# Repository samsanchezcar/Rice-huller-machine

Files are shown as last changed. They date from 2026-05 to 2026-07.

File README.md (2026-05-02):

<div align="center">

# DAMSPI-150
## Descascaradora de Arroz Modular Semiautomática con Pesaje Integrado

**Proyecto Aplicado de Ingeniería — 2017275 | 1er Semestre 2026**
**Universidad Nacional de Colombia · Facultad de Ingeniería · Grupo B**






</div>

---

## Tabla de Contenido

1. [Resumen Ejecutivo](#1-resumen-ejecutivo)
2. [Equipo de Trabajo](#2-equipo-de-trabajo)
3. [Estructura del Repositorio](#3-estructura-del-repositorio)
4. [Arquitectura del Sistema](#4-arquitectura-del-sistema)
5. [Guía de Fase del Proyecto](#5-guía-de-fase-del-proyecto)
6. [Proveedores Clave](#6-proveedores-clave)
7. [Instrucciones de Uso](#7-instrucciones-de-uso)
8. [Estado de Componentes](#8-estado-de-componentes)
9. [Pendientes por Fase](#9-pendientes-por-fase)
10. [Normas y Convenciones del Repositorio](#10-normas-y-convenciones-del-repositorio)

---

## 1. Resumen Ejecutivo

El **DAMSPI-150** es un equipo semiautomático para el descascarillado de arroz paddy (*Oryza sativa*) diseñado para operar en campo, sin acceso a red eléctrica, con capacidad de **150 kg/h**. Surge de la necesidad de los pequeños y medianos productores de arroz de la región de Neiva (Huila) de reducir su dependencia de los molinos industriales y aumentar el valor agregado de su producto en origen.

El sistema está organizado en **4 módulos desmontables** con peso máximo de 25 kg cada uno, permitiendo su transporte y montaje por dos o tres personas sin herramientas especializadas. Incorpora un **sistema de control automático de pesaje** que detiene el proceso al alcanzar el peso de un bulto objetivo (10, 25 o 50 kg), accionando el embrague electromagnético y la compuerta de la tolva.

| Parámetro | Valor |
|---|---|
| Nombre del sistema | DAMSPI-150 |
| Solicitante | Diego Alexander Castro Neira — Diego Castro Industria y Construcción S.A.S. |
| Capacidad objetivo | 150 kg/h de arroz paddy (humedad 18–22%) |
| Motor | Gasolina 6.5 HP / 3600 RPM (ya adquirido) |
| Módulos | 4 módulos desmontables (Potencia, Descascarillado, Control/Pesaje, Chasis) |
| Peso máx. por módulo | ≤ 25 kg |
| Presupuesto total | $7.000.000 COP (aportado por solicitante) |
| Presupuesto estimado | ~$5.980.000 COP (margen de ~$1.020.000) |
| Microcontrolador | PIC18F4550 |
| Interfaz de usuario | LCD 20×4 I2C + Teclado matricial 4×4 |
| Embrague | Electromagnético DC 24V — DLD6-05 tipo A |
| Eficiencia descascarillado | ≥ 85% en primera pasada |
| Precisión pesaje | ±100 g |
| Tiempo de ensamble | ≤ 60 minutos |
| Piezas estructurales | Manufactura aditiva FDM (PETG / PLA+) con optimización topológica previa |
| Semestre | 1er Semestre 2026 (14 semanas: 3 Feb – 30 May 2026) |

---

## 2. Equipo de Trabajo

| Nombre | Código | Área Principal | Responsabilidades Clave |
|---|---|---|---|
| **Nicolás Herreño Fuentes** | — | Diseño Mecánico (Líder) | Cálculos de transmisión, memorias de cálculo, CAD Onshape, planos de fabricación |
| **Sebastián D. Millan B.** | — | Diseño Mecánico | Cálculos elementos de máquinas, CAD, diseño eje secundario |
| **Andrés G. Pinilla M.** | — | Manufactura y CAD | Talleres externos, Onshape, optimización topológica + FDM |
| **Samuel D. Sánchez C.** | — | Electrónica / Control / **Gestión** | Firmware PIC18F4550, sistema de pesaje, **gestión de proveedores, cotizaciones, BOM, compras**, finanzas |
| **Gabriel E. Bojacá M.** | — | Electrónica / Financiero | Circuito electrónico, PCB, interfaz LCD-teclado, gestión presupuesto |
| **Santiago Ávila C.** | — | Eléctrico / Potencia | Alternador, carga batería, cableado potencia, sistema eléctrico Módulo 1 |

> **Nota de gestión**: Samuel es el responsable único de toda la coordinación con proveedores: contacto inicial, solicitud de cotizaciones, seguimiento de pedidos, recepción de componentes y registro en el BOM. Toda compra debe quedar registrada antes de ejecutarse.

---

## 3. Estructura del Repositorio

```
DAMSPI-150/
│
├── README.md                          ← Este archivo — guía maestra del proyecto
│
├── 01_Informe/                        ← Informes de avance (Partes I, II y III)
│   ├── Informe_Avance_Parte_I_Descascaradora.docx   ← Entrega S4 (completada)
│   ├── Informe_Parte_II_Diseño_Detallado.docx        ← Entrega S8 (en progreso)
│   ├── Informe_Parte_III_Final.docx                  ← Entrega S14 (pendiente)
│   ├── boceto_arquitectura_modular.png
│   ├── sistema_potencia_electrica.svg
│   └── Diagramas_bloques.pdf
│
├── 02_Actas/                          ← Actas semanales y documentos legales
│   ├── Acuerdo_Solicitante.pdf        ← AS firmado
│   ├── contrato_social.pdf            ← CS firmado
│   ├── Acta_S01.pdf
│   ├── Acta_S02.pdf
│   ├── Acta_S03.pdf
│   └── Acta_SColchon.pdf
│
├── 03_Cronograma_GANTT/               ← Planificación y seguimiento
│   ├── GANTT_Descascaradora_v2.xlsx   ← GANTT original (referencia)
│   └── GANTT-PAI1B.pdf
│
├── 04_BOM/                            ← Lista de materiales
│   └── BOM_Descascaradora_v1.xlsx     ← BOM con 34 ítems (~$5.98M COP)
│
├── 05_CAD_Planos/                     ← Modelos 3D y planos de fabricación
│   ├── Onshape_Link.md                ← Enlace al modelo Onshape compartido
│   └── (exportar aquí planos PDF/DWG al finalizar cada módulo)
│
├── 06_Estado_del_Arte_Referencias/    ← Literatura técnica y normativa
│   ├── Baker_Tribologia_Molineria_Arroz.pdf
│   ├── Design_Fabrication_Rice_Hulling.pdf
│   ├── Manual_Tecnico_Descascaradora_Referencia.pdf
│   ├── Referencia_Adicional_Procesamiento_Arroz.pdf
│   └── rm05.pdf
│
├── 07_Bitacoras/                      ← Bitácoras semanales individuales
│   ├── Bitacora_Nicolas.md
│   ├── Bitacora_Sebastian.md
│   ├── Bitacora_Andres.md
│   ├── Bitacora_Samuel.md
│   ├── Bitacora_Gabriel.md
│   └── Bitacora_Santiago.md
│
├── 08_Electronica/                    ← Todo lo electrónico (MCU, sensores, firmware)
│   ├── GUIA_ELECTRONICA.md            ← Guía técnica electrónica completa ★
│   ├── firmware/                      ← Código fuente PIC18F4550
│   │   ├── DAMSPI150.X/              ← Proyecto MPLAB X
│   │   └── LibLCD_I2C_XC8.h         ← Librería LCD I2C para XC8
│   └── esquematicos/                  ← Esquemáticos del circuito de control
│
├── 09_Electrica/                      ← Todo lo eléctrico (potencia, alternador, batería)
│   ├── GUIA_ELECTRICA.md             ← Guía técnica eléctrica-potencia completa ★
│   └── diagramas/                     ← Diagramas del sistema de potencia eléctrica
│
└── 10_Gestion/                        ← Gestión del proyecto
    ├── GESTION_PROYECTO.md            ← EDT detallado + Gantt + gestión compras ★
    ├── REGISTRO_PROVEEDORES.md        ← Contactos, cotizaciones y seguimiento (Samuel)
    └── CONTROL_PRESUPUESTO.md        ← Control de gastos vs. presupuesto
```

> Los archivos marcados con **★** son documentos técnicos vivos que deben actualizarse semanalmente.

---

## 4. Arquitectura del Sistema

El DAMSPI-150 se organiza en cuatro módulos funcionales independientes:

```
┌─────────────────────────────────────────────────────────────────────┐
│                    DAMSPI-150 — VISTA FUNCIONAL                     │
├──────────────┬──────────────────┬──────────────────┬───────────────┤
│  MÓDULO 1    │    MÓDULO 2      │    MÓDULO 3       │  MÓDULO 4     │
│  POTENCIA    │  DESCASCARILLADO │  CONTROL/PESAJE   │  CHASIS       │
│              │                  │                   │               │
│ Motor 6.5HP  │  Rodillos PU     │  PIC18F4550       │  Estructura   │
│ Alternador   │  Ø80mm / 200mm   │  LCD 20×4 I2C     │  acero 40×40  │
│ Batería 24V  │  Ventilador      │  Teclado 4×4      │  Chasis       │
│ Embrague     │  centrífugo      │  HX711 + 4 celdas │  soldado      │
│ Boost 14→24V │  Sin Fín alim.   │  SSR + Embrague   │  Ruedas       │
│ Buck 24→5V   │  Pulidora horiz. │  Servo tolva      │  Pasadores    │
│              │  (opcional)      │  Pilotos / Buzzer │  conex. rápida│
│  ~22 kg      │  ~18 kg          │  ~8 kg            │  ~15 kg       │
└──────────────┴──────────────────┴──────────────────┴───────────────┘
       │                │                  │                │
       └────────────────┴──────────────────┴────────────────┘
                    Correas en V / Poleas / Ejes de transmisión
```

**Documentación técnica por área:**

| Área | Documento | Responsable |
|---|---|---|
| Sistema electrónico (MCU, firmware, sensores, interfaz) | [`08_Electronica/GUIA_ELECTRONICA.md`](08_Electronica/GUIA_ELECTRONICA.md) | Samuel, Gabriel |
| Sistema eléctrico (potencia, alternador, batería, carga) | [`09_Electrica/GUIA_ELECTRICA.md`](09_Electrica/GUIA_ELECTRICA.md) | Santiago, Samuel |
| Gestión, EDT, Gantt, proveedores, compras | [`10_Gestion/GESTION_PROYECTO.md`](10_Gestion/GESTION_PROYECTO.md) | Samuel |

---

## 5. Guía de Fase del Proyecto

### Semana Actual → Ver `10_Gestion/GESTION_PROYECTO.md` para detalle completo

| Fase | Semanas | Estado | Entregable |
|---|---|---|---|
| **F1** — Formulación y requisitos | S1–S3 | ✅ Completada | Informe Parte I |
| **F2** — Diseño Módulo Potencia | S3–S6 | 🔄 En progreso | Memorias cálculo + CAD |
| **F3** — Diseño Electrónico y Control | S4–S7 | 🔄 En progreso | Circuito + Firmware |
| **F4** — Diseño Módulo Descascarillado | S3–S8 | 🔄 En progreso | Informe Parte II |
| **F4G** — Gestión proveedores y compras | S3–S10 | 🔄 En progreso | Registro Proveedores |
| **F5** — Manufactura y montaje | S8–S12 | ⏳ Pendiente | Prototipo ensamblado |
| **F6** — Validación y pruebas | S12–S13 | ⏳ Pendiente | Video + resultados |
| **F7** — Documentación y entrega | S13–S14 | ⏳ Pendiente | Informe Parte III |

### Checklist de la Semana en Curso

Antes de cada reunión semanal, verificar:

- [ ] Acta de la semana anterior firmada y archivada en `02_Actas/`
- [ ] Bitácoras individuales actualizadas en `07_Bitacoras/`
- [ ] BOM actualizado con nuevas adquisiciones o cotizaciones (`04_BOM/`)
- [ ] Samuel: actualizar `10_Gestion/REGISTRO_PROVEEDORES.md` con estado de pedidos
- [ ] Avance de CAD subido a Onshape (link en `05_CAD_Planos/Onshape_Link.md`)
- [ ] Samuel/Gabriel: commits de firmware en `08_Electronica/firmware/`
- [ ] GANTT actualizado con estado real de avance

---

## 6. Proveedores Clave

| Proveedor | Productos | Contacto | Responsable |
|---|---|---|---|
| **Solagro Colombia** | Rodillos PU Ø80mm, pulidora horizontal, repuestos | solagro.co/repuestos | Samuel |
| **MercadoLibre Colombia** | Embrague DLD6-05, SSR, electrónica general | mercadolibre.com.co | Samuel |
| **AliExpress** | Celdas de carga tipo S, PIC18F4550, batería LiFePO4, LCD 20×4, teclado 4×4 | aliexpress.com | Samuel |
| **Homecenter** | Motor 6.5HP (ya adquirido) | homecenter.com.co | — |
| **Ferreterías industriales Bogotá** | Perfiles acero, tornillería, rodamientos, poleas | Local Bogotá | Gabriel / Samuel |
| **Taller externo UNAL** | Mecanizado ejes, soldadura chasis | Campus UNAL | Nicolás, Andrés |
| **Naylampmechatronics** | HX711, electrónica | naylampmechatronics.com | Samuel |
| **Siesa Industrial** | E-Stop, pilotos LED industriales | Local Bogotá | Samuel |

> **Ver detalle completo de cotizaciones y contactos en:** [`10_Gestion/REGISTRO_PROVEEDORES.md`](10_Gestion/REGISTRO_PROVEEDORES.md)

---

## 7. Instrucciones de Uso

### Informe Principal
1. Abrir `01_Informe/Informe_Avance_Parte_*.docx` en Word/Google Docs
2. Actualizar tabla de contenido: **Referencias → Actualizar tabla → Todo el documento**
3. No modificar estructura de secciones sin actualizar el TOC

### BOM
- Abrir `04_BOM/BOM_Descascaradora_v1.xlsx`
- Totales calculados automáticamente (columna H = E × G)
- **Columna Estado**: `ADQUIRIDO` / `COTIZADO` / `Por adquirir` / `Por adquirir (Solagro)`
- Actualizar inmediatamente al recibir cualquier componente o cotización
- Samuel notifica al grupo cada actualización

### GANTT
- Abrir `03_Cronograma_GANTT/GANTT_Descascaradora_v2.xlsx`
- Actualizar al inicio de cada semana con estado real
- EDT completo y mejorado en `10_Gestion/GESTION_PROYECTO.md`

### Firmware (Electrónica)
- Abrir `08_Electronica/firmware/DAMSPI150.X/` con **MPLAB X IDE ≥ 6.0**
- Compilador: **XC8 ≥ 3.0**
- Programador: **PICkit 3 o PICkit 4** (ICSP)
- Ver documentación completa en `08_Electronica/GUIA_ELECTRONICA.md`

### CAD (Onshape)
- Link al modelo compartido en `05_CAD_Planos/Onshape_Link.md`
- Exportar planos PDF/DWG a `05_CAD_Planos/` al completar cada módulo
- Usar prefijo de versión: `v1.0_`, `v1.1_`, etc.

---

## 8. Estado de Componentes

| N° | Componente | Módulo | Precio Unit. | Estado | Resp. |
|----|---|---|---|---|---|
| 1 | Motor gasolina 6.5HP | Mod.1 | $750.000 | ✅ ADQUIRIDO | — |
| 2 | Embrague DLD6-05 24V | Mod.1 | $300.000 | 📋 COTIZADO | Samuel |
| 3 | Celda de carga tipo S 10kg ×4 | Mod.3 | $57.045 c/u | 📋 COTIZADO | Samuel |
| 4 | PIC18F4550 DIP-40 | Mod.3 | $31.018 | 📋 COTIZADO | Samuel |
| 5 | Batería LiFePO4 24V/5Ah | Mod.1 | $250.000 | 📋 COTIZADO | Santiago |
| 6 | HX711 ADC 24 bits | Mod.3 | $15.000 | 🛒 Por adquirir | Samuel |
| 7 | LCD 20×4 + módulo I2C | Mod.3 | $25.000 | 🛒 Por adquirir | Samuel |
| 8 | Teclado matricial 4×4 | Mod.3 | $15.000 | 🛒 Por adquirir | Samuel |
| 9 | Rodillos PU Ø80mm (par) | Mod.2 | $400.000 | 🔍 Solagro | Samuel |
| 10 | Pulidora horizontal | Mod.2 | $600.000 | 🔍 Solagro | Samuel |
| 11 | Alternador motocicleta | Mod.1 | $180.000 | 🛒 Por adquirir | Santiago |
| … | *(ver BOM completo)* | — | — | — | — |

> Leyenda: ✅ Adquirido | 📋 Cotizado | 🛒 Por adquirir | 🔍 En gestión con proveedor específico

---

## 9. Pendientes por Fase

### Fase Actual (S4–S7) — Diseño Detallado

**Mecánica (Nicolás, Sebastián, Andrés):**
- [ ] Memorias de cálculo: eje secundario, transmisión por poleas
- [ ] Diseño CAD Módulo 2: rodillos, ajustador, ventilador, Sin Fín
- [ ] Diseño CAD Módulo 4: chasis, puntos de conexión rápida
- [ ] Optimización topológica de piezas para FDM (Andrés)
- [ ] Contacto con taller externo para mecanizado de ejes

**Electrónica (Samuel, Gabriel):**
- [ ] Diseño esquemático PCB del circuito de control (Módulo 3)
- [ ] Iniciar firmware: `initPorts()`, `initLCD_I2C()`, `hx711_init()`
- [ ] Selección y pedido: LCD 20×4, teclado 4×4, HX711, SSR

**Eléctrica (Santiago, Samuel):**
- [ ] Diseño detallado: alternador → rectificador → boost → batería
- [ ] Cotización del Boost DC-DC 14V→24V 5A
- [ ] Diseño de canaletas y cableado entre módulos

**Gestión (Samuel):**
- [ ] Contactar Solagro para rodillos y pulidora (cotización formal)
- [ ] Confirmar pedido AliExpress: celdas de carga, PIC, batería
- [ ] Actualizar REGISTRO_PROVEEDORES.md con tiempos de entrega

### Siguiente Entrega (Parte II — Semana 8)
- [ ] Diseño conceptual con bocetos de todos los módulos
- [ ] Diagramas de caja negra y caja gris
- [ ] Memorias de cálculo completas (transmisión, rodillos, ejes)
- [ ] Modelos CAD 3D avanzados en Onshape
- [ ] Planos preliminares de fabricación
- [ ] Cronograma definitivo actualizado

---

## 10. Normas y Convenciones del Repositorio

### Nomenclatura de Archivos
```
[Módulo]_[Descripción]_v[X.Y].[ext]
Ejemplos:
  Mod3_Esquematico_Control_v1.0.pdf
  Mod1_CAD_BaseMotor_v2.1.step
  Acta_S05_20260310.pdf
```

### Versionado de Documentos
- `v1.0` → Primera versión entregable
- `v1.X` → Correcciones menores (sin cambio de estructura)
- `v2.0` → Revisión mayor (cambio de diseño o nueva fase)

### Convenciones de Código (Firmware)
- Comentarios en español
- Funciones: `camelCase` (ej. `realizarTara()`)
- Constantes: `MAYUSCULAS_CON_GUION` (ej. `PESO_OBJETIVO_KG`)
- Un archivo por módulo funcional (ver `08_Electronica/GUIA_ELECTRONICA.md`)

### Actualización del BOM
- Toda compra, cotización o cambio de precio debe registrarse el mismo día
- Samuel envía resumen semanal al grupo por WhatsApp/Discord
- Los precios en el BOM son precios de compra real (no estimados)

---

## Información del Solicitante

| Campo | Valor |
|---|---|
| Nombre | Diego Alexander Castro Neira |
| Empresa | Diego Castro Industria y Construcción S.A.S. |
| NIT | 9009608102 |
| Correo | dicaindustria@gmail.com |
| Teléfono | 315-255-2560 |
| Ubicación de entrega | Neiva, Huila, Colombia |

---

*Versión: 2.0 | Última actualización: Abril 2026 | Equipo Grupo B — PAI 2017275*

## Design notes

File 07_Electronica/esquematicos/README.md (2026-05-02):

# Esquemáticos — Módulo 3 Control y Pesaje

## Archivos a generar (ver GUIA_ELECTRONICA.md §5 para especificaciones)

| Archivo | Descripción | Estado |
|---|---|---|
| `Mod3_Esquematico_Control_v1.0.pdf` | Circuito completo MCU + sensores + actuadores | ⏳ Gabriel S6–S7 |
| `Mod3_Esquematico_Potencia_v1.0.pdf` | Circuito SSR + embrague + pilotos | ⏳ Gabriel S6 |
| `Mod3_PCB_Layout_v1.0.pdf` | Layout PCB para fabricación JLCPCB | ⏳ Gabriel S7–S8 |

## Herramientas recomendadas
- **KiCad 8** (gratuito, exporta Gerbers para JLCPCB)
- **EasyEDA** (alternativa online, integrado con JLCPCB)

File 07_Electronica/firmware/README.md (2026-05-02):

# Firmware DAMSPI-150 — PIC18F4550

## Requisitos

| Herramienta | Versión mínima |
|---|---|
| MPLAB X IDE | 6.0 |
| XC8 Compiler | 3.0 |
| Programador | PICkit 3 o PICkit 4 |

## Compilar

1. Abrir MPLAB X IDE
2. **File → Open Project** → seleccionar carpeta `DAMSPI150.X/`
3. Verificar Device: `PIC18F4550`, Compiler: `XC8`
4. **Clean and Build** (Ctrl+Shift+F11)
5. El `.hex` queda en `dist/default/production/`

## Programar

Conexión ICSP (5 pines):

```
PICkit 4    →   PIC18F4550
─────────────────────────
MCLR (VPP)  →   Pin 1  (MCLR/VPP)
VDD         →   Pin 11 (VDD +5V)
GND         →   Pin 12 (VSS GND)
PGD (ICSPD) →   Pin 40 (RB7/PGD)
PGC (ICSPC) →   Pin 39 (RB6/PGC)
```

## Calibración del Sistema de Pesaje

**Primera vez o tras cambiar celdas de carga:**

1. Dejar la plataforma de pesaje completamente vacía
2. Energizar el sistema → ejecutar tara automática al inicio
3. Colocar una masa de referencia conocida (ej. 5 kg certificados)
4. Leer el valor raw del HX711 (via UART debug en RC6/RC7)
5. Calcular: `factor_calibracion = (raw_con_masa - offset_tara) / masa_kg`
6. Actualizar la constante en el firmware y recompilar, O usar la opción de calibración del menú LCD

## Estructura del Firmware

```
DAMSPI150.c         ← Archivo principal (main + ISR + toda la lógica)
LibLCD_I2C_XC8.h    ← Driver LCD 20x4 via I2C PCF8574
```

## Mapa EEPROM

| Dirección | Contenido |
|---|---|
| 0x00 | Contador de bultos |
| 0x01 | Reservado |
| 0x02 | Peso objetivo (kg, entero) |
| 0x03 | offset_tara byte HI |
| 0x04 | offset_tara byte MID |
| 0x05 | offset_tara byte LO |
| 0x06 | factor_calibracion byte HI |
| 0x07 | factor_calibracion byte LO |

## Pines del PIC18F4550

Ver tabla completa en `08_Electronica/GUIA_ELECTRONICA.md §5.2`

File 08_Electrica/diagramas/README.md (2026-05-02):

# Diagramas Sistema Eléctrico de Potencia

## Archivos a generar (ver GUIA_ELECTRICA.md para especificaciones)

| Archivo | Descripción | Estado |
|---|---|---|
| `Diagrama_Unifilar_Sistema_Electrico_v1.0.pdf` | Diagrama unifilar completo del sistema eléctrico | ⏳ Santiago S8 |
| `Diagrama_Cableado_Modulos_v1.0.pdf` | Cableado entre módulos (colores, secciones, conectores) | ⏳ Santiago S8–S9 |
| `Esquema_Carga_Bateria_v1.0.pdf` | Circuito carga LiFePO4 (alternador → boost → XH-M603 → batería) | ⏳ Santiago S7 |

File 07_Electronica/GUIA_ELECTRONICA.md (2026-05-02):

# GUÍA TÉCNICA DE SISTEMA ELECTRÓNICO
## DAMSPI-150 — Descascaradora de Arroz Modular Semiautomática con Pesaje Integrado
### Proyecto Aplicado de Ingeniería 2017275 — Universidad Nacional de Colombia — Grupo B — 1er Semestre 2026

---

## OBJETIVO GENERAL

Definir, especificar e integrar todos los componentes electrónicos, eléctricos y de control del sistema DAMSPI-150, de manera que el equipo de diseño cuente con una guía técnica detallada, clara y verificable para la adquisición, montaje, programación y validación del subsistema electrónico completo.

---

## OBJETIVOS ESPECÍFICOS

- Describir la arquitectura electrónica completa del sistema, identificando los tres niveles: potencia eléctrica, adquisición de señal y control lógico.
- Especificar técnicamente cada componente electrónico requerido: microcontrolador, módulos de conversión, actuadores, sensores e interfaz de usuario.
- Documentar el diagrama de bloques del sistema de control y el diagrama del sistema de potencia eléctrica.
- Establecer las conexiones eléctricas entre los módulos del sistema de control y los actuadores y sensores.
- Definir los requerimientos de firmware del PIC18F4550 para la gestión del ciclo de pesaje y control del embrague.
- Proveer la lista de materiales electrónicos con referencias comerciales y especificaciones de adquisición.

---

## 1. DEFINICIÓN DEL PROBLEMA ELECTRÓNICO

El sistema DAMSPI-150 opera en campo abierto (zona rural de Neiva, Huila) **sin acceso a la red eléctrica**. La totalidad de la energía eléctrica del sistema electrónico y de control debe ser generada de forma autónoma a partir del motor de gasolina de 6.5 HP ya adquirido. Esto implica un doble problema de ingeniería electrónica:

1. **Generación y acondicionamiento de energía eléctrica**: El motor mecánico debe alimentar un sistema eléctrico que incluye un embrague electromagnético de 24 VDC y un sistema de control lógico de 5 V, con autonomía mínima de 4 horas continuas.

2. **Control automático del pesaje**: El sistema debe medir en tiempo real la masa del arroz procesado que cae sobre una plataforma de pesaje, y actuar sobre el embrague electromagnético y la válvula de la tolva al alcanzar el peso objetivo configurado por el operario (10 kg, 25 kg o 50 kg).

El sistema electrónico se integra en el **Módulo 3 — Control, Pesaje e Interfaz**, con la excepción del sistema de potencia eléctrica que pertenece al **Módulo 1 — Potencia**.

---

## 2. ARQUITECTURA GENERAL DEL SISTEMA ELECTRÓNICO

El sistema electrónico se divide en **tres capas funcionales** interconectadas:

```mermaid
flowchart TD
    subgraph C1["CAPA 1 — GENERACIÓN Y DISTRIBUCIÓN DE POTENCIA (Módulo 1)"]
        M1[Motor Gasolina 6.5HP] --> ALT[Alternador 100-200W]
        ALT --> RECT[Rectificador + Regulador 14V DC]
        RECT --> BOOST[Boost DC-DC 14V a 24V]
        BOOST --> BAT[Batería LiFePO4 24V / 5Ah + BMS]
        BAT --> BUCK[Buck DC-DC 24V a 5V 3A]
    end

    subgraph C2["CAPA 2 — ADQUISICIÓN Y CONTROL LÓGICO (Módulo 3)"]
        PIC[PIC18F4550 DIP-40 / 8MHz]
        HX[HX711 ADC 24 bits]
        CELLS[4x Celdas de carga Tipo S / 10 kg]
        LCD[LCD 20x4 I2C PCF8574 5V nativo]
        KP[Teclado Matricial 4x4 16 teclas]
        ESTOP_R[E-Stop NC lectura estado]
        BUZ[Buzzer 5V]
        LEDS[Pilotos LED Verde / Amarillo / Rojo]
        CELLS --> HX --> PIC
        PIC <--> LCD
        KP --> PIC
        ESTOP_R --> PIC
        PIC --> BUZ
        PIC --> LEDS
    end

    subgraph C3["CAPA 3 — ACTUADORES ELECTROMECÁNICOS"]
        SSR[SSR 24VDC/10A]
        ESTOP_HW[E-Stop NC acción HW directa]
        EMB[Embrague DLD6-05 DC 24V + Diodo flyback]
        SRV[Servo MG996R válvula tolva / PWM]
        SSR --> ESTOP_HW --> EMB
        PIC --> SSR
        PIC --> SRV
    end

    C1 -->|24 VDC Embrague + SSR| C3
    BUCK -->|5 VDC MCU sensores pantalla| C2
    BAT -->|24 VDC| SSR
```

> **Ventaja clave del nuevo diseño**: Al reemplazar la Nokia 5110 (3.3 V) por el LCD 20×4 I2C y los 4 botones por un teclado matricial 4×4, **todo el sistema de control opera a 5 V nativo**. Se elimina el regulador de 3.3 V, los divisores de nivel resistivos y se libera el bus SPI para uso exclusivo del HX711.

---

## 3. SISTEMA DE POTENCIA ELÉCTRICA (MÓDULO 1)

### 3.1 Diagrama de Flujo de Energía

```mermaid
flowchart TD
    MOTOR["Motor Gasolina 6.5HP\n3600 RPM eje mecánico"]
    ALT["Alternador de Motocicleta\n100 a 200 W AC trifásico"]
    RECT["Rectificador + Regulador\nSalida: 13.8 a 14.5 V DC"]
    BOOST["Boost DC-DC\n14V a 24V / 5A / η mayor 85%\n+ Módulo XH-M603"]
    BAT["Batería LiFePO4\n24V / 5Ah + BMS 6S 15A\nAutonomía mayor 4h"]
    BUCK["Buck DC-DC\n24V a 5V / 3A\nLM2596 / MP1584"]
    SSR["SSR 24VDC/10A\n+ E-Stop NC en serie"]
    EMB["Embrague DLD6-05\n24 VDC / menor 5A\n+ Diodo flyback 1N4007"]
    PIC["PIC18F4550\n5V"]
    HX711["HX711\n5V"]
    SERVO["Servo MG996R\n5V"]
    BUZ["Buzzer\n5V"]
    LCD20["LCD 20x4\n+ PCF8574 I2C\n5V nativo"]
    KP4["Teclado 4x4\n5V nativo"]

    MOTOR -->|eje mecánico| ALT
    ALT -->|AC trifásico| RECT
    RECT -->|13.8 a 14.5V DC| BOOST
    BOOST -->|24V DC| BAT
    BAT -->|24V DC| SSR
    SSR -->|24V conmutado| EMB
    BAT -->|24V DC| BUCK
    BUCK -->|5V| PIC
    BUCK -->|5V| HX711
    BUCK -->|5V| SERVO
    BUCK -->|5V| BUZ
    BUCK -->|5V| LCD20
    BUCK -->|5V| KP4
```

### 3.2 Componentes del Sistema de Potencia Eléctrica

| N° | Componente | Especificación Técnica | Función |
|----|---|---|---|
| 1 | Alternador de motocicleta | 100–200 W, AC trifásico, 3000–5000 RPM | Generación de energía eléctrica desde el eje del motor |
| 2 | Rectificador + regulador de moto | Puente de diodos 15 A + regulador. Salida: 13.8–14.5 V DC | Conversión AC→DC y regulación |
| 3 | Convertidor DC-DC Boost | Entrada: 13.8–14.5 V / Salida: 24 V, 5 A, η ≥ 85% | Elevar tensión para carga de batería 24 V |
| 4 | Batería LiFePO4 | 24 V / 5 Ah, BMS integrado, I_desc_max = 10 A | Fuente centralizada de energía 24 V |
| 5 | Convertidor DC-DC Buck | LM2596 o MP1584. Entrada: 24 V / Salida: 5 V, 3 A | Alimentar MCU, sensores, pantalla, servomotor y buzzer |
| 6 | Módulo de carga XH-M603 | Control de carga para baterías de litio | Protección de la batería LiFePO4 durante la carga |
| 7 | BMS 6S 15A 24V | Protección batería: sobretemperatura, sobrecorriente | Integrado o externo a la batería |

> **Nota de diseño**: El motor de combustión y el alternador deben ubicarse en posición **lateral** respecto al área de procesamiento de arroz, con el escape del motor dirigido al exterior.

---

## 4. MANUFACTURA ADITIVA Y OPTIMIZACIÓN TOPOLÓGICA

### 4.1 Estrategia de Diseño

La mayoría de las piezas estructurales que no están sujetas a cargas de impacto elevado (carcasas, soportes, guías, montajes de sensores, tapas del panel de control) se fabricarán mediante **manufactura aditiva FDM**. El proceso de diseño sigue esta secuencia:

```mermaid
flowchart LR
    TO["1. Optimización\nTopológica\nEspacio de diseño\ncargas y restricciones\nGeometría óptima\ncomo punto de partida"]
    CAD["2. Diseño CAD\nInterpretación de la\ngeometría optimizada\nAdaptación para FDM\nángulos soportes tolerancias"]
    SIM["3. Simulación FEM\nVerificación de\nesfuerzos deformaciones\ny factor de seguridad"]
    AM["4. Manufactura\nAditiva FDM\nImpresión 3D PETG o PLA+\nInsertos de calor\nPost-procesado"]
    INTG["5. Integración\nMontaje con\nelementos comerciales\ny componentes\nelectrónicos"]

    TO --> CAD --> SIM --> AM --> INTG
```

### 4.2 Secuencia de Diseño — Del Subsistema de Salida a la Base

El diseño sigue la secuencia **desde los elementos de mayor complejidad funcional hacia la base de la máquina**, de modo que cada componente ascendente ya tiene definidas sus restricciones geométricas:

| Paso | Subsistema | Componentes impresos clave | Material |
|---|---|---|---|
| 1 | Tolva de salida + válvula servo | Guía de flujo, soporte MG996R | PETG |
| 2 | Plataforma de pesaje | Soporte celdas tipo S, guías laterales | PLA+ |
| 3 | Panel de control (Módulo 3) | Carcasa con ventana LCD + teclado | PLA+ / PETG |
| 4 | Soporte del embrague y transmisión | Protector embrague, canaleta de cables | PETG |
| 5 | Estructura del chasis y base | Tapas laterales, canaletas, pies | PLA+ |

### 4.3 Parámetros de Manufactura Aditiva

| Parámetro | Valor |
|---|---|
| Tecnología | FDM (filamento fundido) |
| Material estructural | PETG (Tg ≈ 80°C, mayor resistencia química) |
| Material carcasas | PLA+ |
| Relleno piezas estructurales | 40–60%, patrón gyroid |
| Relleno carcasas | 20–30%, patrón cuadrícula |
| Capas perimetrales | ≥ 4 |
| Insertos roscados | Insertos de calor M3 y M4 (knurled heat insert) |
| Tolerancia ensambles | ±0.3 mm en partes deslizantes |

### 4.4 Integración de Sensores y Finales de Carrera en el CAD

Los sensores y elementos de seguridad se consideran **desde la fase de optimización topológica**, no como añadidos posteriores:

- **Celdas de carga tipo S**: los agujeros de montaje M6 son restricciones fijas en la optimización topológica del soporte de plataforma.
- **Servomotor MG996R**: el soporte incluye la geometría del brazo de palanca integrada al cuerpo impreso.
- **Finales de carrera** (si se incorporan): hendiduras de alojamiento con prensacables definidas antes de la geometría final.
- **Rutas de cableado**: modeladas como restricciones de "zona libre de material" en la optimización, garantizando el paso de cables sin interferencias.
- **Módulo PCF8574 + LCD**: la ventana de la carcasa del panel de control se define con las dimensiones exactas del módulo LCD 20×4 y el teclado 4×4 como restricciones de diseño.

---

## 5. MICROCONTROLADOR — PIC18F4550

### 5.1 Especificaciones

| Parámetro | Valor |
|---|---|
| Fabricante | Microchip Technology Inc. |
| Arquitectura | RISC 8 bits, Harvard |
| Memoria Flash | 32 KB |
| RAM | 2 KB |
| EEPROM | 256 bytes |
| Frecuencia máxima | 48 MHz (USB) / 40 MHz (general) |
| Oscilador interno | 8 MHz ajustable |
| Entradas ADC | 13 canales, 10 bits |
| Comunicaciones | USART, MSSP (SPI + **I2C**), USB 2.0 Full Speed |
| Timers | Timer0 (8/16 bit), Timer1, Timer2, Timer3 |
| PWM | CCP1 (RC2), CCP2 (RC1) |
| Pines I/O | 35 pines digitales (Puertos A, B, C, D, E) |
| Encapsulado | DIP-40 |
| Tensión de operación | 2.0 V – 5.5 V |
| Referencia Datasheet | DS39632E — Microchip (2009) |

### 5.2 Asignación de Pines — LCD I2C + Teclado 4×4

```mermaid
flowchart LR
    subgraph PB["PORTB — Teclado Matricial 4x4"]
        RB0["RB0 → Fila 1 salida activo bajo"]
        RB1["RB1 → Fila 2 salida activo bajo"]
        RB2["RB2 → Fila 3 salida activo bajo"]
        RB3["RB3 → Fila 4 salida activo bajo"]
        RB4["RB4 ← Col 1 entrada KBI pull-up"]
        RB5["RB5 ← Col 2 entrada KBI pull-up"]
        RB6["RB6 ← Col 3 entrada KBI pull-up"]
        RB7["RB7 ← Col 4 entrada KBI pull-up"]
    end

    subgraph PC["PORTC — Comunicaciones"]
        RC2["RC2/CCP1 → PWM Servo 50Hz"]
        RC3["RC3/SCL → I2C LCD PCF8574"]
        RC4["RC4/SDA ↔ I2C LCD PCF8574"]
        RC6["RC6/TX → UART debug opcional"]
        RC7["RC7/RX ← UART debug opcional"]
    end

    subgraph PD["PORTD — Actuadores y HX711"]
        RD0["RD0 → HX711 SCK bit-bang"]
        RD1["RD1 ← HX711 DOUT bit-bang"]
        RD3["RD3 → SSR Embrague ON/OFF"]
        RD4["RD4 → Buzzer 5V"]
        RD5["RD5 → LED Verde 2N2222"]
        RD6["RD6 → LED Amarillo 2N2222"]
        RD7["RD7 → LED Rojo 2N2222"]
    end

    subgraph PA["PORTA/E — Control y Botones"]
        RA4["RA4 ← E-Stop NC pull-up 10k"]
        RA5["RA5 ← BTN Start NA pull-up 10k"]
        RE0["RE0 ← BTN Stop NC pull-up 10k"]
    end
```

### 5.3 Configuración del Oscilador y Defines

```c
#pragma config FOSC   = INTOSCIO_EC  // Oscilador interno 8 MHz
#pragma config WDT    = OFF
#pragma config PWRT   = ON
#pragma config MCLRE  = ON
#pragma config LVP    = OFF
#pragma config PBADEN = OFF          // PORTB digital al reset
#pragma config BOR    = OFF

#define _XTAL_FREQ   8000000UL
#define LCD_ADDR     0x27            // Dirección I2C PCF8574
#define HX_SCK       RD0
#define HX_DOUT      RD1
#define SSR_PIN      RD3
#define SERVO_PIN    RC2             // CCP1 PWM hardware
#define BUZZER_PIN   RD4
#define ESTOP_PIN    RA4             // E-Stop NC (LOW = presionado)
#define START_PIN    RA5
#define STOP_PIN     RE0
```

---

## 6. SISTEMA DE PESAJE — CELDAS DE CARGA Y HX711

### 6.1 Celdas de Carga Tipo S (×4)

| Parámetro | Valor |
|---|---|
| Capacidad nominal | 10 kg por celda |
| Capacidad total (4 en puente) | 40 kg (rango útil: 0–60 kg) |
| Señal de salida | 2 mV/V nominal |
| Excitación | 5–10 VDC |
| Protección | IP67 |
| Conexión | 4 hilos (Exc+, Exc-, Out+, Out-) |
| Error de linealidad | < 0.05% del fondo de escala |

#### 6.1.1 Configuración en Puente de Wheatstone Completo

```mermaid
flowchart TB
    EXCP(["Exc+ 5V"])
    EXCM(["Exc- GND"])
    OUTP(["Out+ a HX711 A+"])
    OUTM(["Out- a HX711 A-"])

    EXCP --> C1["Celda 1\nR+dR tensión"]
    EXCP --> C3["Celda 3\nR-dR compresión"]
    C1 --> OUTP
    C3 --> OUTM
    OUTP --> C2["Celda 2\nR-dR compresión"]
    OUTM --> C4["Celda 4\nR+dR tensión"]
    C2 --> EXCM
    C4 --> EXCM
```

> V_out_max = 5V × 2 mV/V × 2 = **20 mV diferencial** → amplificado por HX711 con ganancia ×128 → 2.56 V al ADC de 24 bits.

### 6.2 Módulo HX711

| Parámetro | Valor |
|---|---|
| Resolución | 24 bits |
| Ganancia canal A | 128× (25 pulsos SCK) |
| Tasa de muestreo | 80 SPS (pin RATE a VCC) |
| Tensión de alimentación | 5 V |
| CMRR | Mín. 100 dB |
| Interfaz MCU | 2 pines: DOUT + SCK (bit-bang) |

---

## 7. INTERFAZ DE USUARIO — LCD 20×4 I2C Y TECLADO MATRICIAL

### 7.1 Pantalla LCD 20×4 con Módulo I2C PCF8574

| Parámetro | Valor |
|---|---|
| Resolución | 20 caracteres × 4 filas |
| Controlador LCD | HD44780 o compatible |
| Módulo adaptador | PCF8574 (expansor I2C de 8 bits) |
| Interfaz con PIC | I2C — solo **2 pines**: RC3 (SCL) y RC4 (SDA) |
| Velocidad I2C | 100 kHz (Standard) / 400 kHz (Fast) |
| **Tensión lógica** | **5 V nativo — sin adaptadores de nivel** |
| Dirección I2C | 0x27 (A2=A1=A0=VCC) o 0x3F según módulo |
| Retroiluminación | LED, controlada por bit P3 del PCF8574 |
| Precio aproximado | $25.000 COP |

#### 7.1.1 Conexión LCD 20×4 I2C con PIC18F4550

```mermaid
flowchart LR
    PIC["PIC18F4550\nRC3 = SCL\nRC4 = SDA\nVDD = 5V"]
    PCF["Módulo PCF8574\nI2C Addr: 0x27\nPull-up 4.7kΩ a 5V\n(incluido en módulo)"]
    LCD["LCD HD44780\n20x4 caracteres\n5V"]
    BUCK["Buck 5V"]

    PIC -->|"I2C SCL 100kHz"| PCF
    PIC <-->|"I2C SDA"| PCF
    PCF -->|"bus paralelo 4 bits\nEN RS RW BL"| LCD
    BUCK -->|"5V"| PIC
    BUCK -->|"5V"| PCF
    BUCK -->|"5V"| LCD
```

#### 7.1.2 Distribución de la Pantalla LCD 20×4

```
Posicion: 01234567890123456789  (20 columnas)
         ┌────────────────────┐
F1:      │DAMSPI-150 [OPERANDO│  Nombre + Estado actual
F2:      │PESO:   050.000 kg  │  Peso con 3 decimales
F3:      │OBJ:50.0  BLTS: 003 │  Objetivo + contador bultos
F4:      │BAT:███░░ 65% ERR:0 │  Batería estimada + errores
         └────────────────────┘

Estados mostrados en F1:
  [INICIO  ] → Inicializando / tara
  [ESPERA  ] → Listo, embrague libre
  [OPERANDO] → Embrague acoplado, llenando
  [COMPLETO] → Peso objetivo alcanzado
  [  MENU  ] → Navegando configuración
  [E-STOP!!] → Emergencia activa

Pantalla MENU (F1-F4):
  ┌────────────────────┐
  │>>> MENU CONFIG     │
  │> Peso objetivo: 50 │
  │  Tara manual       │
  │  Calibrar sistema  │
  └────────────────────┘
```

### 7.2 Teclado Matricial 4×4

| Parámetro | Valor |
|---|---|
| Tipo | Membrana flexible 4 filas × 4 columnas |
| Teclas | 16 (0–9, A, B, C, D, *, #) |
| Tensión | 3–5 V (compatible directo con PIC a 5 V) |
| Conexión | 8 pines → PORTB completo |
| Precio aproximado | $15.000 COP |

#### 7.2.1 Mapeo de Teclas para DAMSPI-150

```
       COL1(RB4)   COL2(RB5)   COL3(RB6)   COL4(RB7)
F1(RB0): [ 1 ]      [ 2 ]       [ 3 ]      [A = START ]
F2(RB1): [ 4 ]      [ 5 ]       [ 6 ]      [B = STOP  ]
F3(RB2): [ 7 ]      [ 8 ]       [ 9 ]      [C = MENU  ]
F4(RB3): [* = TARA] [ 0 ]       [# = DEL ] [D = OK    ]
```

| Tecla | Función |
|---|---|
| `0`–`9` | Entrada numérica del peso objetivo |
| `A` | START — Iniciar ciclo de llenado |
| `B` | STOP — Detener ciclo manualmente |
| `C` | MENU — Acceder al menú de configuración |
| `D` | OK — Confirmar selección |
| `*` | TARA — Ejecutar tara manual |
| `#` | DELETE — Borrar último dígito ingresado |

#### 7.2.2 Algoritmo de Escaneo del Teclado

```mermaid
flowchart TD
    START(["Inicio escaneo\ndesde ISR PORTB"])
    INIT["Todas las filas en HIGH\nLATB_LO = 0b1111"]

    F1["Fila 1 activa LOW\nLATB = 0b11111110"]
    CHK1{"Col RB4-RB7\nalguna en LOW?"}
    REG1["Tecla Fila 1:\nC1=1 C2=2 C3=3 C4=A"]

    F2["Fila 2 activa LOW\nLATB = 0b11111101"]
    CHK2{"Col activa?"}
    REG2["Tecla Fila 2:\nC1=4 C2=5 C3=6 C4=B"]

    F3["Fila 3 activa LOW\nLATB = 0b11111011"]
    CHK3{"Col activa?"}
    REG3["Tecla Fila 3:\nC1=7 C2=8 C3=9 C4=C"]

    F4["Fila 4 activa LOW\nLATB = 0b11110111"]
    CHK4{"Col activa?"}
    REG4["Tecla Fila 4:\nC1=* C2=0 C3=# C4=D"]

    DEB["Anti-rebote\n__delay_ms(20)"]
    RESTORE["Restaurar LATB = 0b11110000\npara detectar próxima tecla"]
    PROC["ProcesarTecla(tecla)\ncounter = 0\nRBIF = 0"]
    END(["Fin"])

    START --> INIT --> F1
    F1 --> CHK1
    CHK1 -- Si --> REG1 --> DEB
    CHK1 -- No --> F2
    F2 --> CHK2
    CHK2 -- Si --> REG2 --> DEB
    CHK2 -- No --> F3
    F3 --> CHK3
    CHK3 -- Si --> REG3 --> DEB
    CHK3 -- No --> F4
    F4 --> CHK4
    CHK4 -- Si --> REG4 --> DEB
    CHK4 -- No --> RESTORE
    DEB --> RESTORE --> PROC --> END
```

### 7.3 E-Stop y Botones Industriales

| Elemento | Tipo | Pin PIC | Lógica |
|---|---|---|---|
| E-Stop hongo Ø40mm | NC enclavado 10A 24VDC | RA4 (lectura) | LOW = presionado |
| BTN START verde Ø22mm | NA 5A IP65 | RA5 | LOW = presionado |
| BTN STOP rojo Ø22mm | NC 5A IP65 | RE0 | LOW = presionado |

> El E-Stop actúa **directamente en el circuito 24V del SSR** (hardware), independiente del firmware.

---

## 8. ACTUADORES ELECTROMECÁNICOS

### 8.1 Embrague Electromagnético DLD6-05 Tipo A

| Parámetro | Valor |
|---|---|
| Tensión | 24 VDC |
| Corriente | < 5 A nominal ~3–4 A |
| Par | 6 Nm |
| T. respuesta ON | < 0.3 s |
| T. respuesta OFF | < 0.2 s |
| Diámetro eje | 19 mm |

#### 8.1.1 Circuito de Control SSR + E-Stop

```mermaid
flowchart LR
    PIC["PIC18F4550\nRD3 salida digital\n0V / 5V"]
    SSR["SSR 24VDC/10A\naislamiento óptico\nsin rebote mecánico"]
    ESTOP["E-Stop NC\nen serie HW\nindependiente del FW"]
    EMB["Embrague DLD6-05\n24V DC / Par 6 Nm"]
    FLY["Diodo flyback\n1N4007 anti-paralelo\nprotege SSR"]
    BAT["Batería 24V"]

    PIC -->|"0V=desacoplado\n5V=acoplado"| SSR
    BAT -->|"24V DC"| SSR
    SSR -->|"24V conmutado"| ESTOP
    ESTOP -->|"24V si NC cerrado"| EMB
    FLY -.-|"absorbe pico inductivo\nal abrir circuito"| EMB

    style ESTOP fill:#ff4444,color:#fff
    style EMB fill:#2196F3,color:#fff
```

### 8.2 Servomotor MG996R — Válvula de Tolva

| Parámetro | Valor |
|---|---|
| Par | 11 kg·cm @ 6V |
| Señal | PWM T=20 ms pulso 1–2 ms |
| Tensión | 5 V |
| Engranajes | Metálicos (polvo de arroz) |
| Pin PIC | RC2/CCP1 (PWM hardware) |

```c
// PR2 = (8e6 / (4 × 50 × 16)) - 1 = 249
T2CON   = 0b00000011;   // Timer2 ON, prescaler 1:16
PR2     = 249;           // Periodo 20 ms @ 8 MHz
CCP1CON = 0b00001100;   // PWM mode

// Posiciones:
// CERRADA (0°):   CCPR1L = 25   // 1.0 ms / duty 5%
// MEDIA   (90°):  CCPR1L = 37   // 1.5 ms / duty 7.5%
// ABIERTA (180°): CCPR1L = 50   // 2.0 ms / duty 10%
```

---

## 9. INDICADORES DE ESTADO

### 9.1 Pilotos LED 24V (×3) + Buzzer

| Color / Elemento | Estado | Pin PIC | Driver |
|---|---|---|---|
| LED Verde | Operando — embrague acoplado | RD5 | 2N2222 + R 1kΩ |
| LED Amarillo | En espera / embrague libre | RD6 | 2N2222 + R 1kΩ |
| LED Rojo | Error / E-Stop / falla batería | RD7 | 2N2222 + R 1kΩ |
| Buzzer 5V | Alertas sonoras | RD4 | R 47Ω directo |

**Alertas sonoras:**
- 1 beep corto (100 ms): confirmación de tecla
- 2 beeps cortos: inicio de ciclo
- 3 beeps largos (500 ms): objetivo alcanzado
- Beep continuo: emergencia activa

---

## 10. DIAGRAMA DE BLOQUES DEL SISTEMA DE CONTROL

```mermaid
flowchart TB
    subgraph MOD1["Módulo 1 — Potencia"]
        BAT24["Batería 24V LiFePO4"]
        V5["Buck 5V / 3A LM2596"]
    end

    subgraph MOD3["Módulo 3 — Control y Pesaje"]
        subgraph ENTRADAS["Entradas"]
            CELLS["4x Celdas tipo S\npuente Wheatstone"]
            HX["HX711\nADC 24 bits / x128\nRD0=SCK RD1=DOUT"]
            KP["Teclado 4x4\nPORTB completo\nKBI interrupt"]
            START["BTN START\nRA5 / NA"]
            STOP_B["BTN STOP\nRE0 / NC"]
            ESTOP["E-Stop NC\nRA4 lectura estado"]
        end

        PIC["PIC18F4550\nDIP-40 / 8 MHz\nFirmware DAMSPI-150"]

        subgraph SALIDAS["Salidas"]
            LCD["LCD 20x4\nI2C PCF8574\n0x27 / 5V\nRC3=SCL RC4=SDA"]
            SSR["SSR 24VDC/10A\nEmbrague DLD6-05\nRD3"]
            SRV["Servo MG996R\nCCP1 PWM 50Hz\nRC2"]
            BUZ["Buzzer 5V\nRD4"]
            LV["LED Verde\nRD5 + 2N2222"]
            LA["LED Amarillo\nRD6 + 2N2222"]
            LR["LED Rojo\nRD7 + 2N2222"]
        end

        CELLS --> HX -->|"bit-bang RD0/RD1"| PIC
        KP -->|"PORTB KBI ISR"| PIC
        START & STOP_B & ESTOP --> PIC

        PIC -->|"I2C RC3/RC4"| LCD
        PIC -->|"RD3"| SSR
        PIC -->|"CCP1 PWM RC2"| SRV
        PIC --> BUZ & LV & LA & LR
    end

    BAT24 -->|"24V al SSR"| SSR
    V5 -->|"5V"| HX & PIC & SRV & BUZ & LCD & KP
```

---

## 11. DIAGRAMA DE ESTADOS DEL FIRMWARE

```mermaid
stateDiagram-v2
    [*] --> INICIO : RESET

    INICIO : INICIO\ninitPorts / initInterrupts\ninitLCD_I2C / Bienvenida 3s\nCargar calibración EEPROM\nTara automática

    ESPERA : ESPERA\nLED Amarillo ON\nEmbrague DESACOPLADO SSR OFF\nServo CERRADO\nMostrar peso en LCD\nEsperar tecla A o START

    OPERANDO : OPERANDO\nLED Verde ON\nEmbrague ACOPLADO SSR ON\nServo ABIERTO\nLeyendo HX711 5Hz\nActualizando LCD

    COMPLETADO : COMPLETADO\nEmbrague DESACOPLADO\nServo CERRADO\nLED Verde parpadea\n3 beeps largos\nbultos++\nEEPROM guardar

    MENU : MENU\nNavegación con teclado\nPeso objetivo\nTara manual\nCalibración

    EMERGENCIA : EMERGENCIA\nLED Rojo ON\nEmbrague libre HW\nServo CERRADO\nBeep continuo\nLCD E-STOP!!

    INICIO --> ESPERA : tara OK

    ESPERA --> OPERANDO : tecla A / START
    ESPERA --> MENU : tecla C

    MENU --> ESPERA : tecla C o D

    OPERANDO --> COMPLETADO : peso mayor igual objetivo
    OPERANDO --> ESPERA : tecla B / STOP

    COMPLETADO --> ESPERA : tecla D OK\nnueva tara automática

    ESPERA --> EMERGENCIA : E-Stop presionado
    OPERANDO --> EMERGENCIA : E-Stop presionado
    COMPLETADO --> EMERGENCIA : E-Stop presionado
    MENU --> EMERGENCIA : E-Stop presionado

    EMERGENCIA --> ESPERA : E-Stop liberado
```

---

## 12. DIAGRAMAS DETALLADOS DEL FIRMWARE

### 12.1 Flujo General — `main()`

```mermaid
flowchart TD
    A(["Inicio RESET"])
    B["initPorts()\nTRIS LAT UART ADC\nCCP1 PWM I2C MSSP\nPORTB pull-ups RBPU=0"]
    C["initInterrupts()\nRCIE RBIE KBI\nTMR0IE GIE PEIE"]
    D["initLCD_I2C()\nConfigurar PCF8574 0x27\nInicializar HD44780\nOcultarCursor"]
    E{"RI == 0?\nreset por software"}
    F["LCD: Reset software\n__delay_ms(1000)"]
    G{"POR == 0?\nfalla de energía"}
    H["LCD: Falla de energia\n__delay_ms(1000)\nestado = ST_POR"]
    I["LCD: Reset de usuario\n__delay_ms(1000)"]
    J["BorraLCD_I2C()"]
    K{{"switch(estado)\nLoop principal infinito"}}
    POR["ST_POR"]
    STA["ST_START"]
    ASK["ST_ASK"]
    CNT["ST_COUNT"]
    BCK["ST_BACK"]
    EMG["ST_EMERGENCIA"]

    A --> B --> C --> D --> E
    E -- Si --> F --> J
    E -- No --> G
    G -- Si --> H --> J
    G -- No --> I --> J
    J --> K
    K --> POR & STA & ASK & CNT & BCK & EMG
    POR & STA & ASK & CNT & BCK & EMG --> K
```

### 12.2 Estado `ST_POR` — Restauración tras Falla de Energía

```mermaid
flowchart TD
    A["ST_POR"]
    B["Leer EEPROM\ncount = EEPROM_Read(0x00)\nmissing = EEPROM_Read(0x01)\nobjective = EEPROM_Read(0x02)"]
    C["LCD F1: Falla de energia\nLCD F2: Restaurar conteo?\nLCD F3: A=SI   B=NO\nLCD F4: Objetivo: XX kg"]
    D["ok = 0\ntecla = 0\nask = 1"]
    E{"!ok\nesperar tecla"}
    F{"emergency?"}
    G["estado = ST_EMERGENCIA"]
    H{"tecla == A\nSI"}
    I["Restaurar variables\ncount missing objective\nbienvenida = 1\nestado = ST_COUNT\nmostrarLCD()"]
    J{"tecla == B\nNO"}
    K["estado = ST_START"]
    L["LCD: Error de tecla\n__delay_ms(1000)"]
    M["ask = 0"]

    A --> B --> C --> D --> E
    E -- esperando --> F
    F -- Si --> G
    F -- No --> E
    E -- ok=1 --> H
    H -- Si --> I --> M
    H -- No --> J
    J -- Si --> K --> M
    J -- No --> L --> E
```

### 12.3 Estado `ST_START` — Bienvenida e Inicialización

```mermaid
flowchart TD
    A["ST_START"]
    B["bienvenida_lcd()\nAnimación en LCD 20x4\nbanda corriendo izq a der"]
    C["LCD: DAMSPI-150\nLCD: Iniciando..."]
    D["bienvenida = 1\nobjective = 0\ncount = 0\nmissing = 0\ncounter = 0"]
    E["realizar_tara()\n32 muestras HX711\npromediar\nguardar offset_tara"]
    F{"Tara OK?\nerror menor umbral"}
    G["LED Verde parpadea\nLCD: Tara correcta\nbeep corto\n__delay_ms(500)"]
    H["LED Rojo ON\nLCD: Error tara\nbeep doble"]
    I{"3 intentos\nfallidos?"}
    J["LED Rojo parpadea\nLCD: Verificar celdas\nbuzzer continuo\nestado = ST_EMERGENCIA"]
    K["ok = 0\nestado = ST_ASK"]

    A --> B --> C --> D --> E --> F
    F -- Si --> G --> K
    F -- No --> H --> I
    I -- No --> E
    I -- Si --> J
```

### 12.4 Estado `ST_ASK` — Ingreso del Peso Objetivo

```mermaid
flowchart TD
    A["ST_ASK"]
    B["input = 0\nobjective = 0\nBorraLCD()\nLCD F1: Peso objetivo:\nLCD F2: ___ kg\nLCD F3: rango 0-60 kg\nLCD F4: D=OK  #=Borrar"]
    C["ask = 1\nok = 0\nMostrarCursorLCD()"]
    D{"!ok\nesperar teclado"}
    E{"emergency?"}
    F["estado = ST_EMERGENCIA"]
    G{"input < 2?"}
    H["objective = objective / 10\ntecla = 0\ncaso 1 digito ingresado"]
    I["input = 3"]
    J["objective += tecla\nya tenemos 2 digitos"]
    K{"objective mayor 60\no objective == 0?"}
    L["LCD: Valor errado!\nLCD: Rango 1-60 kg\n__delay_ms(1500)\nestado = ST_START"]
    M["missing = objective\ncount = 0\nEEPROM_Write(0x02, objective)\nestado = ST_COUNT"]

    A --> B --> C --> D
    D -- esperando --> E
    E -- Si --> F
    E -- No --> D
    D -- ok=1 --> G
    G -- Si input<2 --> H --> I
    G -- No --> I
    I --> J --> K
    K -- Si --> L
    K -- No --> M
```

### 12.5 Estado `ST_COUNT` — Ciclo de Pesaje Principal

```mermaid
flowchart TD
    A["ST_COUNT\nSSR ON embrague acoplado\nServo ABIERTO\nLED Verde ON"]
    B["LCD F1: DAMSPI-150 OPERANDO\nLCD F2: PESO: 000.000 kg\nLCD F3: OBJ:XX.X BLT:NNN\nLCD F4: B=STOP C=MENU"]
    C{"count != objective?"}
    D["leer_HX711_x16()\nmedia movil N=16"]
    E["peso_kg = calcular_peso(raw)\n= (raw - offset_tara) / factor_cal"]
    F["Actualizar LCD F2:\nPESO: XXX.XXX kg"]
    G{"peso_kg mayor\nigual objetivo?"}
    H["SSR OFF embrague libre\nServo CERRADO\nBeep triple LARGO\nLED Verde parpadea\ncount++\nmissing--\nbultos++\nEEPROM_Write(0x00 count)\nEEPROM_Write(0x01 missing)"]
    I["estado = ST_BACK"]
    J{"emergency?"}
    K["estado = ST_EMERGENCIA"]
    L{"tecla == B\no BTN_STOP?"}
    M["SSR OFF\nServo CERRADO\nestado = ST_ESPERA"]
    N{"tecla == C\nMENU?"}
    O["estado = ST_MENU"]
    P["__delay_ms(200)\n5 Hz de actualización"]

    A --> B --> C
    C -- Si --> D --> E --> F --> G
    G -- Si peso>=obj --> H --> I
    G -- No --> J
    J -- Si --> K
    J -- No --> L
    L -- Si --> M
    L -- No --> N
    N -- Si --> O
    N -- No --> P --> C
    C -- No count==obj --> H
```

### 12.6 Estado `ST_BACK` — Confirmación de Bulto Completado

```mermaid
flowchart TD
    A["ST_BACK"]
    B["LCD F1: COMPLETADO!\nLCD F2: PESO: XX.XXX kg\nLCD F3: Bultos: NNN\nLCD F4: D=Nuevo  C=Menu"]
    C["LED Verde parpadea x5\nBeep 3 veces largos"]
    D["ok = 0\nesperar tecla D"]
    E{"emergency?"}
    F["estado = ST_EMERGENCIA"]
    G{"tecla == D\nnuevo ciclo?"}
    H["realizar_tara()\nobjective = 0\ninput = 0\nSSR OFF\nServo CERRADO\nLEDs OFF"]
    I["estado = ST_START"]
    J{"tecla == C\nmenu?"}
    K["estado = ST_MENU"]

    A --> B --> C --> D
    D -- esperando --> E
    E -- Si --> F
    E -- No --> D
    D -- ok=1 --> G
    G -- Si --> H --> I
    G -- No --> J
    J -- Si --> K
    J -- No --> D
```

### 12.7 Estado `ST_EMERGENCIA`

```mermaid
flowchart TD
    A["ST_EMERGENCIA"]
    B["SSR OFF refuerzo SW\nHW ya actua por E-Stop NC"]
    C["Servo CERRADO"]
    D["LED Rojo ON\nLED Verde OFF\nLED Amarillo OFF"]
    E["LCD F1: !!EMERGENCIA!!\nLCD F2: E-STOP ACTIVO\nLCD F3: Libere el boton\nLCD F4: para continuar"]
    F["Buzzer continuo"]
    G{"ESTOP_PIN == HIGH?\nE-Stop liberado\ngiro fisico"}
    H["Buzzer OFF\nLED Rojo OFF\nLCD: E-Stop liberado\n__delay_ms(2000)"]
    I["realizar_tara()\nestado = ST_ESPERA"]

    A --> B --> C --> D --> E --> F --> G
    G -- No presionado --> G
    G -- Si liberado --> H --> I
```

### 12.8 `hx711_leer_raw()` — Lectura 24 bits Bit-Bang SPI

```mermaid
flowchart TD
    A(["hx711_leer_raw()"])
    B["GIE = 0\ndeshabilitar interrupciones\ndurante lectura critica"]
    C{"DOUT == HIGH?\nHX711 ocupado"}
    D["Esperar..."]
    E["raw = 0\ni = 0"]
    F{"i < 24?"}
    G["SCK = HIGH\n__delay_us(1)"]
    H["raw = raw << 1"]
    I{"DOUT == HIGH?"}
    J["raw OR= 1"]
    K["SCK = LOW\n__delay_us(1)\ni++"]
    L["Pulso 25 Ganancia 128x\nSCK=HIGH delay SCK=LOW"]
    M{"raw AND 0x800000?\nbit de signo 24 bits"}
    N["raw OR= 0xFF000000\nextension de signo a 32 bits"]
    O["GIE = 1"]
    P(["return int32_t raw"])

    A --> B --> C
    C -- Si --> D --> C
    C -- No --> E --> F
    F -- Si --> G --> H --> I
    I -- Si --> J --> K --> F
    I -- No --> K
    F -- No i=24 --> L --> M
    M -- Si --> N --> O
    M -- No --> O
    O --> P
```

### 12.9 `hx711_leer_promedio()` — Filtro de Media Móvil N=16

```mermaid
flowchart TD
    A(["hx711_leer_promedio(N=16)"])
    B["buffer[16] = 0\nindex = 0\nsum = 0\ni = 0"]
    C{"i < N?"}
    D["raw = hx711_leer_raw()"]
    E{"raw fuera de rango HW?\nraw==0x7FFFFF\no raw==0x800000"}
    F["Descartar muestra\nerror de lectura\n__delay_ms(10)"]
    G["sum -= buffer[index]\nbuffer[index] = raw\nsum += raw\nindex = (index+1) % 16\ni++"]
    H["__delay_ms(12)\n80 SPS = 12.5 ms/muestra"]
    I["promedio = sum / N"]
    J(["return promedio"])

    A --> B --> C
    C -- Si --> D --> E
    E -- Si --> F --> C
    E -- No --> G --> H --> C
    C -- No i=16 --> I --> J
```

### 12.10 `calcular_peso()` — Aplicar Calibración

```mermaid
flowchart TD
    A(["calcular_peso(raw)"])
    B["peso_neto = raw - offset_tara"]
    C{"peso_neto < 0?"}
    D["peso_neto = 0\nevitar pesos negativos"]
    E["peso_kg = float(peso_neto)\n/ factor_calibracion"]
    F{"peso_kg mayor RANGO_MAX\n60.0 kg?"}
    G["peso_kg = RANGO_MAX\nset flag overrange"]
    H(["return peso_kg"])

    A --> B --> C
    C -- Si --> D --> E
    C -- No --> E
    E --> F
    F -- Si --> G --> H
    F -- No --> H
```

### 12.11 `realizar_tara()` — Calibración de Cero

```mermaid
flowchart TD
    A(["realizar_tara()"])
    B["LCD: Ejecutando tara...\nNo colocar peso"]
    C["32 muestras HX711\nhx711_leer_raw() x32\ndescartar primeras 4"]
    D["offset_tara = promedio(muestras 5-32)"]
    E["EEPROM_Write(ADDR_OFFSET_HI\noffset_tara >> 16)"]
    F["EEPROM_Write(ADDR_OFFSET_MID\n(offset_tara >> 8) AND 0xFF)"]
    G["EEPROM_Write(ADDR_OFFSET_LO\noffset_tara AND 0xFF)"]
    H["LCD: Tara completada\nBeep corto\n__delay_ms(500)"]
    I(["return"])

    A --> B --> C --> D --> E --> F --> G --> H --> I
```

### 12.12 `ISR()` — Rutina de Interrupción Completa

```mermaid
flowchart TD
    A(["__interrupt() ISR"])

    T0{"TMR0IF == 1?\noverflow Timer0\ncada 500 ms"}
    T0A["medioSegundo = !medioSegundo"]
    T0B{"medioSegundo == 1?"}
    T0C["actualizarBateria()\nestimar nivel\npor tensión buck"]
    T0D["counter++"]
    T0E{"counter >= 40?"}
    T0F["LCD_BL = 0 backlight OFF\nSSR = OFF\nSLEEP() ahorro energía"]
    T0G{"counter >= 20?"}
    T0H["LCD_BL = 0\napagar retroiluminación"]
    T0I["TMR0 = 49911\nTMR0IF = 0\nLED_CPU ^= 1"]

    RBIF{"RBIF == 1?\ncambio en PORTB\ntecla presionada"}
    RBIFA{"PORTB != 0b11110000?\ncolumna activa"}
    RBIFB["escaneo_teclado()\nrow scanning 4 filas\nregistrar tecla"]
    RBIFC["ProcesarTecla(tecla)\ncounter = 0"]
    RBIFD["__delay_ms(20)\nanti-rebote\nRBIF = 0"]

    END(["Fin ISR"])

    A --> T0
    T0 -- Si --> T0A --> T0B
    T0B -- Si --> T0C --> T0D
    T0B -- No --> T0D
    T0D --> T0E
    T0E -- Si --> T0F --> T0I
    T0E -- No --> T0G
    T0G -- Si --> T0H --> T0I
    T0G -- No --> T0I

    T0 -- No --> RBIF
    T0I --> RBIF
    RBIF -- Si --> RBIFA
    RBIFA -- Si --> RBIFB --> RBIFC --> RBIFD --> END
    RBIFA -- No --> RBIFD
    RBIF -- No --> END
```

### 12.13 `ProcesarTecla()` — Lógica de Teclas del Teclado 4×4

```mermaid
flowchart TD
    A(["ProcesarTecla(tecla)"])
    NUM{"tecla entre\n0 y 9?"}
    NUMA{"ask == 1\ny input < 2?"}
    NUMB["input++\nobjective = objective*10\n+ valor numerico\nMostrar digito en LCD"]

    TA{"tecla == A\nSTART?"}
    TAA{"estado == ESPERA?"}
    TAB["SSR = ON\nServo = ABIERTO\nestado = ST_COUNT"]

    TB{"tecla == B\nSTOP?"}
    TBA{"estado == ST_COUNT?"}
    TBB["SSR = OFF\nServo = CERRADO\nestado = ST_ESPERA"]

    TC{"tecla == C\nMENU?"}
    TCA["estado = ST_MENU"]

    TD{"tecla == D\nOK?"}
    TDA["ok = 1"]

    TS{"tecla == asterisco\nTARA?"}
    TSA["realizar_tara()"]

    TH{"tecla == numeral\nDELETE?"}
    THA{"input > 0?"}
    THB["input--\nobjective = objective / 10\nBorrar ultimo digito LCD"]

    END(["Fin"])

    A --> NUM
    NUM -- Si --> NUMA
    NUMA -- Si --> NUMB --> END
    NUMA -- No --> END
    NUM -- No --> TA
    TA -- Si --> TAA
    TAA -- Si --> TAB --> END
    TAA -- No --> END
    TA -- No --> TB
    TB -- Si --> TBA
    TBA -- Si --> TBB --> END
    TBA -- No --> END
    TB -- No --> TC
    TC -- Si --> TCA --> END
    TC -- No --> TD
    TD -- Si --> TDA --> END
    TD -- No --> TS
    TS -- Si --> TSA --> END
    TS -- No --> TH
    TH -- Si --> THA
    THA -- Si --> THB --> END
    THA -- No --> END
    TH -- No --> END
```

### 12.14 `EEPROM_Write()` y `EEPROM_Read()`

```mermaid
flowchart LR
    subgraph WRITE["EEPROM_Write(addr, data)"]
        W1["EEADR = addr\nEEDATA = data"]
        W2["EEPGD = 0\nCFGS = 0\nWREN = 1"]
        W3["GIE = 0\ndeshabilitar IRQ\ndurante unlock"]
        W4["EECON2 = 0x55\nEECON2 = 0xAA\nsecuencia unlock"]
        W5["WR = 1\niniciar escritura"]
        W6{"WR == 1?\nen curso"}
        W7["WREN = 0\nGIE = 1"]
        W1 --> W2 --> W3 --> W4 --> W5 --> W6
        W6 -- Si --> W6
        W6 -- No --> W7
    end

    subgraph READ["EEPROM_Read(addr)"]
        R1["EEADR = addr"]
        R2["EEPGD = 0\nCFGS = 0"]
        R3["RD = 1\niniciar lectura"]
        R4(["return EEDATA"])
        R1 --> R2 --> R3 --> R4
    end
```

**Mapa de direcciones EEPROM:**

| Dirección | Variable | Descripción |
|---|---|---|
| `0x00` | `count` | Bultos completados en el ciclo actual |
| `0x01` | `missing` | Bultos faltantes |
| `0x02` | `objective` | Peso objetivo (kg entero) |
| `0x03` | `offset_HI` | Byte alto offset de tara |
| `0x04` | `offset_MID` | Byte medio offset de tara |
| `0x05` | `offset_LO` | Byte bajo offset de tara |
| `0x06` | `factor_HI` | Byte alto factor de calibración |
| `0x07` | `factor_LO` | Byte bajo factor de calibración |
| `0x08` | `config_flags` | bit0=idioma, bit1=brillo LCD |

### 12.15 Estructura de Módulos del Firmware

```mermaid
flowchart TD
    MAIN["main.c\ninitPorts\ninitInterrupts\ninitLCD_I2C\nLoop principal\nMaquina de estados"]

    CONFIG["config.h\npragma config\nDefines pines\nDefines constantes\nTipos globales"]

    HX["hx711.c / .h\nhx711_leer_raw\nhx711_leer_promedio\ncalcular_peso\nrealizar_tara"]

    LCD["lcd_i2c.c / .h\ninitLCD_I2C\nMensajeLCD_I2C\nDireccionaLCD_I2C\nBorraLCD_I2C\nEscribeLCD_c\nbacklight ON OFF"]

    KP["teclado.c / .h\nescaneo_teclado\nProcesarTecla\ngetTecla"]

    PESAJE["pesaje.c / .h\nFSM estados\nbienvenida_lcd\nmostrar_peso_lcd\nmostrar_menu_lcd\ngestionar_inactividad"]

    ACTU["actuadores.c / .h\nSSR_ON SSR_OFF\nservo_abrir\nservo_cerrar\nservo_posicion"]

    ALRT["alertas.c / .h\nbeep_corto\nbeep_completado\nbeep_emergencia\nled_estado"]

    EEPROM["eeprom.c / .h\nEEPROM_Write\nEEPROM_Read\nguardar_calibracion\ncargar_calibracion"]

    MAIN --> CONFIG & HX & LCD & KP & PESAJE & ACTU & ALRT & EEPROM
```

---

## 13. LISTA DE MATERIALES ELECTRÓNICOS (BOM v2.0)

### Módulo 3 — Control, Pesaje e Interfaz

| N° | Componente | Cant. | Especificación | Precio Unit. COP | Total COP | Estado | Proveedor |
|----|---|---|---|---|---|---|---|
| 1 | PIC18F4550 DIP-40 | 1 | 32KB Flash, 8MHz int., I2C, SPI, ADC | $31.000 | $31.000 | Cotizado | AliExpress ítem 1005008943635084 |
| 2 | Celda de carga tipo S 10 kg | 4 | Aluminio, IP67, 2mV/V, 4 hilos | $14.260 | $57.040 | Cotizado | AliExpress ítem 1005008612967612 |
| 3 | Módulo HX711 | 1 | ADC 24 bits, ganancia 128x, 80 SPS | $15.000 | $15.000 | Por adquirir | MercadoLibre |
| 4 | LCD 20x4 + módulo I2C PCF8574 | 1 | HD44780, 5V, I2C 0x27, 20x4 chars | $25.000 | $25.000 | Por adquirir | MercadoLibre / AliExpress |
| 5 | Teclado matricial 4x4 membrana | 1 | 16 teclas, 5V, 8 pines a PORTB | $15.000 | $15.000 | Por adquirir | MercadoLibre / AliExpress |
| 6 | Relé de estado sólido SSR | 1 | DC-DC 24V control, 10A carga | $25.000 | $25.000 | Por adquirir | MercadoLibre Colombia |
| 7 | Servomotor MG996R | 1 | 11 kg·cm, PWM 50Hz, 5V, engranes metálicos | $35.000 | $35.000 | Por adquirir | MercadoLibre / AliExpress |
| 8 | Buck DC-DC 24V→5V 3A | 2 | LM2596 o MP1584 | $12.000 | $24.000 | Por adquirir | MercadoLibre |
| 9 | E-Stop hongo Ø40mm NC | 1 | 10A, 24VDC, rojo, enclavado mecánico | $25.000 | $25.000 | Por adquirir | MercadoLibre / Siesa Industrial |
| 10 | Botón START verde Ø22mm | 1 | NA, 5A, industrial, IP65 | $15.000 | $15.000 | Por adquirir | MercadoLibre |
| 11 | Botón STOP rojo Ø22mm | 1 | NC, 5A, industrial, IP65 | $15.000 | $15.000 | Por adquirir | MercadoLibre |
| 12 | Pilotos LED 24V (x3 colores) | 3 | Ø22mm, cuerpo metálico, 24VDC, IP65 | $12.000 | $36.000 | Por adquirir | MercadoLibre / Siesa |
| 13 | Buzzer activo 5V | 1 | Mayor 80 dB, 5VDC, oscilador interno | $5.000 | $5.000 | Por adquirir | MercadoLibre |
| 14 | Transistor NPN 2N2222 | 5 | 600 mA, 40V, TO-92 | $2.000 | $10.000 | Por adquirir | Electrónicas Bogotá |
| 15 | Diodo 1N4007 | 5 | 1A, 1000V, flyback y protección | $1.000 | $5.000 | Por adquirir | Electrónicas Bogotá |
| 16 | Resistencias 10kΩ 1kΩ 330Ω 47Ω | 1 lote | 1/4W, 5% | $6.000 | $6.000 | Por adquirir | Electrónicas Bogotá |
| 17 | Condensadores 100nF 10µF 100µF | 1 lote | Desacople MCU e I2C | $5.000 | $5.000 | Por adquirir | Electrónicas Bogotá |
| 18 | PCB fabricada o protoboard FR4 | 1 | Montaje circuito de control | $25.000 | $25.000 | Por adquirir | MercadoLibre |
| 19 | Caja de control IP54 | 1 | Con ventana para LCD 20x4 y teclado | $45.000 | $45.000 | Por adquirir | Ferreterías industriales |
| 20 | Conectores JST con latch | 1 lote | Cables entre módulos antivibración | $10.000 | $10.000 | Por adquirir | MercadoLibre |
| | **SUBTOTAL MÓDULO 3** | | | | **$419.040** | | |

> Componentes eliminados vs BOM v1.0: Nokia 5110 (-$15.000), LM1117-3.3 (-$3.000), pulsadores x4 (-$8.000), resistencias divisor nivel (-$2.000). Ahorro: $28.000. Costo adicional: LCD 20x4 (+$25.000), Teclado 4x4 (+$15.000). **Diferencia neta: +$12.000 COP con interfaz muy superior.**

### Módulo 1 — Sistema de Potencia Eléctrica

| N° | Componente | Cant. | Especificación | Precio Unit. COP | Total COP | Estado |
|----|---|---|---|---|---|---|
| E1 | Alternador de motocicleta 100–200W | 1 | AC trifásico, 14V rectificado | $180.000 | $180.000 | Por adquirir |
| E2 | Rectificador + regulador 14V | 1 | Puente diodos 15A + regulador moto | $35.000 | $35.000 | Por adquirir |
| E3 | Boost DC-DC 14V→24V 5A | 1 | Eficiencia mayor 85% | $45.000 | $45.000 | Por adquirir |
| E4 | Batería LiFePO4 24V/5Ah + BMS | 1 | BMS integrado, autonomía mayor 4h | $250.000 | $250.000 | Cotizado |
| E5 | Módulo de carga XH-M603 | 1 | Control carga baterías litio | $25.000 | $25.000 | Por adquirir |
| | **SUBTOTAL MÓDULO 1** | | | | **$535.000** | |

> **Total componentes electrónicos**: ~$954.040 COP (dentro del presupuesto global de $7.000.000 COP)

---

## 14. CONSIDERACIONES DE DISEÑO ELÉCTRICO Y EMC

### 14.1 Separación de Masas

```mermaid
flowchart TB
    subgraph POT["GND_POTENCIA"]
        BAT_G["Batería 24V"]
        ALT_G["Alternador"]
        EMB_G["Embrague 24V"]
        SSR_G["SSR carga"]
    end

    subgraph LOG["GND_LÓGICA"]
        BUCK_G["Buck 5V / GND"]
        PIC_G["PIC18F4550"]
        HX_G["HX711"]
        CELLS_G["Celdas de carga Exc-"]
        LCD_G["LCD 20x4 + PCF8574"]
        KP_G["Teclado 4x4"]
    end

    STAR(["PUNTO DE ESTRELLA\nUnico punto de union\nGND_POT con GND_LOG\n+ Ferrita si hay ruido"])

    POT --- STAR
    LOG --- STAR

    WARN["No unir masas\nen multiples puntos\ncrea bucles de tierra\ny acopla ruido al HX711"]
    STAR -.-> WARN
```

### 14.2 Filtrado I2C y Desacople

- Pull-up I2C: **4.7 kΩ a +5V** (generalmente incluidos en el módulo PCF8574).
- Condensador desacople VCC PCF8574: **100 nF cerámico** lo más cerca posible del chip.
- **Longitud máxima cable I2C**: ≤ 30 cm a 100 kHz en este entorno de ruido.
- Si aparecen errores I2C por ruido del alternador: reducir velocidad a **50 kHz** ajustando SSPADD.
- **PCB**: montar sobre standoffs de silicona antivibración dentro de la caja IP54.

---

## 15. PRUEBAS Y VALIDACIÓN

### 15.1 Pruebas de Validación por Subsistema

| ID | Prueba | Procedimiento | Criterio de éxito |
|----|---|---|---|
| P1 | Calibración de pesaje | Masas de 1, 5, 10, 25 y 50 kg | Error < ±100 g en todo el rango |
| P2 | Tara dinámica | Motor encendido, plataforma vacía, 30 min | Deriva < ±300 g en 30 min |
| P3 | Paro automático | Objetivo 5 kg, verter arroz lentamente | SSR OFF al alcanzar 5 kg ±100 g |
| P4 | E-Stop | Presionar durante operación normal | Embrague desacoplado en < 0.5 s |
| P5 | Autonomía batería | Sistema sin motor, batería llena | Operación ≥ 4 horas |
| P6 | Ruido de vibraciones | Motor encendido sin procesar arroz | Fluctuación < ±200 g en lectura |
| P7 | Pantalla LCD I2C | Legibilidad exterior bajo sol | Legible a 1 metro |
| P8 | Teclado matricial | Pulsar cada tecla 10 veces seguidas | Sin fantasmas ni rebotes |
| P9 | Temperatura PCB | 2 horas operación continua | T_PCB < 60°C |
| P10 | Restauración EEPROM | Cortar energía durante ciclo y reiniciar | Ofrece restauración correcta del conteo |

### 15.2 Protocolo de Puesta en Marcha

```mermaid
flowchart TD
    S1["1. Verificar conexiones de potencia\nPolaridad batería\nOrientación SSR\nDiodo flyback embrague"]
    S2["2. Energizar solo el buck 5V\nSin conectar embrague\nVerificar 5.0V ±0.25V en bornes PIC"]
    S3["3. Cargar firmware via ICSP\nPICkit 3 o 4\nVerificar suma de verificación"]
    S4["4. Verificar pantalla LCD I2C\nDebe mostrar: DAMSPI-150\nDirección 0x27 detectada\nRetroiluminación ON"]
    S5["5. Verificar teclado matricial\nProbar cada tecla en modo diagnóstico\nVerificar tecla correcta en LCD"]
    S6["6. Calibrar celdas de carga\nTara con plataforma vacía\nCalibar con masa de referencia conocida"]
    S7["7. Probar E-Stop y SSR\nSin motor con embrague desconectado\nVerificar corte en menos 0.5 s"]
    S8["8. Prueba de ciclo completo\nConectar todo\nCiclo real con masa de referencia"]

    S1 --> S2 --> S3 --> S4 --> S5 --> S6 --> S7 --> S8
```

---

## 16. HERRAMIENTAS DE DESARROLLO

| Herramienta | Uso | Observación |
|---|-----|---|
| MPLAB X IDE mayor 6.0 | Entorno de desarrollo PIC18F4550 | Gratuito Microchip |
| XC8 Compiler mayor 3.0 | Compilador C para PIC 8 bits | Versión free suficiente |
| PICkit 3 o 4 | Programador/depurador ICSP | 5 pines: MCLR PGD PGC VDD GND |
| Multímetro digital | Verificación tensiones y continuidad | Resolución mV corriente hasta 10 A |
| Osciloscopio | Verificar PWM 50 Hz e I2C 100 kHz | Recomendado para depuración HX711 |
| Analizador lógico | Depurar bus I2C SCL/SDA | Mayor 8 canales 24 MHz muestreo |
| Fuente variable 0-30V 3A | Pruebas sin motor | Para simular batería 24V |
| Masas de calibración certificadas | Calibración del pesaje | 1 kg 5 kg 10 kg de precisión conocida |
| Fusion 360 Generative Design o nTopology | Optimización topológica piezas impresas | — |
| Cura o Bambu Studio | Slicer FDM preparación de impresión | — |

---

## 17. REFERENCIA RÁPIDA DE PARÁMETROS CLAVE

| Parámetro | Valor |
|---|---|
| Microcontrolador | PIC18F4550, DIP-40, 8 MHz interno |
| Pantalla | LCD 20×4 HD44780 + PCF8574 I2C, 5V, dir. 0x27 |
| Teclado | Matricial 4×4 membrana, PORTB, KBI ISR |
| Tensión sistema de control | 5 V DC sin regulador 3.3V |
| Tensión embrague | 24 V DC menos 5 A |
| Tensión batería | 24 V LiFePO4 5 Ah |
| Resolución de pesaje | 24 bits HX711 resolución efectiva ~1 g |
| Rango de pesaje | 0–60 kg |
| Precisión | ±100 g requerimiento / ~±21 g esperado |
| Frecuencia actualización peso | 5 Hz (80 SPS dividido 16 promedio) |
| Frecuencia PWM servo | 50 Hz período 20 ms CCP1 hardware |
| Velocidad I2C LCD | 100 kHz Standard Mode |
| Tiempo respuesta embrague | < 0.5 s SSR + DLD6-05 |
| Autonomía batería | Mayor 4 horas |
| Protección IP caja | Mínimo IP54 |
| Temperatura operación | 10–40°C Neiva Huila |
| Material estructural impreso | PETG infill 40-60% mayor 4 perímetros |
| Material carcasas impresas | PLA+ infill 20-30% |

---

## REFERENCIAS

- Microchip Technology Inc. (2009). *PIC18F4550 Datasheet* (DS39632E). Chandler, AZ, EE.UU.
- AVIA Semiconductor. (2016). *HX711 24-bit ADC for Weigh Scales: Datasheet*. Xiamen, China.
- NXP Semiconductors. (2021). *PCF8574 Remote 8-bit I/O expander for I2C bus* (Rev. 7). Eindhoven, Países Bajos.
- Hitachi. (1998). *HD44780U LCD-II: Dot Matrix LCD Controller/Driver*. Tokio, Japón.
- Ministerio de Trabajo de Colombia. (1979). *Resolución 2400 de 1979: Estatuto de seguridad industrial*. Bogotá, Colombia.
- ISO 11684:1995. *Tractors and machinery for agriculture — Safety signs and hazard pictorials*. Ginebra, Suiza.
- ISO 4254-1:2013. *Agricultural machinery — Safety — Part 1: General requirements*. Ginebra, Suiza.
- Sanchez C., S. D. (2025). *PIC Conveyor — PIC18F4550 — Sistema de banda transportadora* (Repositorio de referencia). Universidad Nacional de Colombia.
- Informe de Avance Parte I — DAMSPI-150 (2026). Grupo B, PAI 2017275, Universidad Nacional de Colombia.

---

*Guía Técnica v2.0 | Abril 2026 | Proyecto PAI 2017275 — Grupo B | Universidad Nacional de Colombia*
*Samuel D. Sanchez C. · Gabriel E. Bojacá M. · Andrés G. Pinilla M. · Nicolás Herreño F. · Santiago Ávila C. · Sebastián D. Millan B.*

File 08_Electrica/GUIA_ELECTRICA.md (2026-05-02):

# GUÍA TÉCNICA — SISTEMA ELÉCTRICO DE POTENCIA
## DAMSPI-150 · Módulo 1 — Generación, Almacenamiento y Distribución de Energía
### Responsable: Santiago Ávila C. (diseño y cableado) · Samuel D. Sánchez C. (gestión compras)

---

## 1. ALCANCE DE ESTA GUÍA

Esta guía cubre **exclusivamente el sistema eléctrico de potencia** del DAMSPI-150: la cadena que va desde el motor de gasolina hasta los bornes de salida de 5 V DC y 24 V DC que alimentan el resto de los módulos. La electrónica de control (MCU, sensores, firmware) está documentada en `08_Electronica/GUIA_ELECTRONICA.md`.

**Lo que cubre esta guía:**
- Alternador de motocicleta acoplado al eje del motor
- Rectificación y regulación AC→DC
- Elevación de tensión (Boost DC-DC 14 V → 24 V)
- Batería LiFePO4 24 V / 5 Ah + BMS
- Sistema de carga inteligente (XH-M603)
- Convertidor Buck DC-DC 24 V → 5 V
- Embrague electromagnético DLD6-05 (24 V DC, parte eléctrica)
- Cableado de potencia entre módulos
- Protecciones: fusibles, E-Stop, diodo flyback

**Lo que NO cubre (ver `08_Electronica/GUIA_ELECTRONICA.md`):**
- PIC18F4550 y firmware
- HX711 y celdas de carga
- LCD 20×4 I2C, teclado matricial
- SSR (parte lógica de control)
- Pilotos LED lógicos y buzzer

---

## 2. ESPECIFICACIONES ELÉCTRICAS DEL SISTEMA

| Parámetro | Valor |
|---|---|
| Fuente primaria | Motor gasolina 6.5 HP / 3600 RPM (ya adquirido) |
| Fuente eléctrica | Alternador de motocicleta 100–200 W |
| Tensión bus principal | 24 V DC (batería LiFePO4) |
| Tensión lógica | 5 V DC (buck converter desde 24 V) |
| Corriente máxima embrague | < 5 A @ 24 V |
| Corriente total sistema (peak) | ~8 A @ 24 V |
| Autonomía sin motor | ≥ 4 horas (batería 5 Ah) |
| Temperatura de operación | 10–45 °C (campo abierto Neiva) |
| Protección IP caja eléctrica | Mínimo IP54 |
| Voltaje de carga batería (LiFePO4) | 29.2 V (4.85 V/celda × 6S) |
| Voltaje de corte descarga | 18.0 V (3.0 V/celda × 6S) |

---

## 3. ARQUITECTURA DEL SISTEMA ELÉCTRICO

```mermaid
flowchart TD
    MOT["Motor Gasolina\n6.5 HP / 3600 RPM\nKohler / Briggs & Stratton\nYa adquirido"]

    subgraph GEN["GENERACIÓN (acoplado al eje del motor)"]
        ALT["Alternador de Motocicleta\n100–200 W AC\nTrifásico o bifásico\n~3000–5000 RPM"]
        RECT["Rectificador de puente\n+ Regulador de voltaje\nSalida: 13.8–14.5 V DC\n15 A máx."]
        ALT --> RECT
    end

    subgraph ALMAC["ALMACENAMIENTO Y CARGA"]
        BOOST["Boost DC-DC\n14 V → 29.2 V carga / 24 V operación\n5 A / η ≥ 85%"]
        CARGADOR["Módulo XH-M603\nControl carga LiFePO4\nCorte sobrevoltaje / subvoltaje"]
        BAT["Batería LiFePO4\n6S2P o 6S1P\n24 V nominal / 5 Ah\n+ BMS 6S 15 A"]
        BOOST --> CARGADOR --> BAT
    end

    subgraph DIST["DISTRIBUCIÓN (desde batería)"]
        F1["Fusible principal\n15 A / 32 V"]
        BUS24["Bus 24 V DC"]
        BUCK["Buck DC-DC\n24 V → 5 V / 3 A\nLM2596 / MP1584"]
        F1 --> BUS24
        BUS24 --> BUCK
    end

    subgraph CARGAS["CARGAS ELÉCTRICAS"]
        EMB["Embrague DLD6-05\n24 V DC / 3–5 A\n+ Diodo flyback 1N4007\n+ SSR 24V/10A"]
        CTRL["Sistema de Control\nMódulo 3\n5 V / ~500 mA total"]
        BUCK --> CTRL
        BUS24 --> EMB
    end

    MOT -->|"eje mecánico\npolea o acoplamiento directo"| ALT
    RECT -->|"13.8–14.5 V DC"| BOOST
    BAT -->|"24 V DC"| F1
```

---

## 4. COMPONENTES DEL SISTEMA ELÉCTRICO

### 4.1 Alternador de Motocicleta

| Parámetro | Valor |
|---|---|
| Tipo | Trifásico o bifásico de imán permanente |
| Potencia nominal | 100–200 W @ velocidad nominal |
| Velocidad de operación | 3000–5000 RPM (acoplado al eje del motor) |
| Tensión AC de salida | 14–18 V AC (sin carga) |
| Tensión DC rectificada | 13.8–14.5 V DC (con regulador) |
| Acoplamiento al motor | Polea conducida Ø80 mm sobre eje secundario, o acoplamiento flexible directo |
| Referencia comercial | Alternador estátor universal de moto 150–200cc (MercadoLibre / repuestos motos) |
| Precio estimado | $180.000 COP |
| Responsable compra | Santiago / Samuel |

> **Criterio de selección**: El alternador debe generar potencia suficiente para cargar la batería mientras el sistema está en operación. Con la batería cargada al 80%, el consumo neto del sistema eléctrico (embrague + control) es de ~175 W. Un alternador de 150 W es suficiente en operación normal; la batería cubre los picos.

> **Acoplamiento mecánico**: Se recomienda usar una polea conducida de Ø80 mm montada sobre el eje secundario de la transmisión del motor, para aprovechar la relación de transmisión y mantener el alternador en su rango óptimo de velocidad. Alternativa: acoplamiento flexible directo al eje del motor.

### 4.2 Rectificador de Puente + Regulador de Voltaje

| Parámetro | Valor |
|---|---|
| Tipo | Rectificador de puente de diodos + regulador IC de motocicleta |
| Corriente máxima | 15 A |
| Tensión de salida | 13.8–14.5 V DC regulada |
| Disipación de calor | Montar sobre perfil de aluminio con pasta térmica |
| Referencia | Regulador rectificador universal de moto (ATV/moto 12V) |
| Precio estimado | $35.000 COP |

> El regulador convencional de motocicleta (tipo shunt) disipa el exceso de potencia como calor. Es robusto y de bajo costo. Para mayor eficiencia se puede usar un MPPT dedicado, pero no es necesario en esta aplicación.

### 4.3 Convertidor Boost DC-DC (14 V → 24 V)

| Parámetro | Valor |
|---|---|
| Topología | Boost (elevador) síncrono |
| Tensión de entrada | 10–16 V DC (rango alternador) |
| Tensión de salida | 24–29.2 V DC ajustable |
| Corriente de salida | 5 A continua |
| Eficiencia | ≥ 85% @ carga nominal |
| Protecciones | Sobrevoltaje, sobrecorriente, temperatura |
| Referencia | Módulo Boost DC-DC XL6009 o LM2587 de alta potencia |
| Precio estimado | $45.000 COP |
| Responsable compra | Samuel |

> **Ajuste**: El potenciómetro del Boost se ajusta para que la tensión de salida sea ~29.2 V cuando el módulo XH-M603 esté en modo carga. En operación con batería ya cargada, el módulo XH-M603 regula y el Boost solo mantiene la tensión flotante.

### 4.4 Módulo de Control de Carga XH-M603

| Parámetro | Valor |
|---|---|
| Función | Controlador de carga inteligente para baterías de litio |
| Tensión máx. de carga (LiFePO4 6S) | 29.2 V |
| Tensión mín. de descarga | 18.0 V (corte automático) |
| Corriente de carga máxima | 10 A (ajustable) |
| Indicador | LED bicolor + display de voltaje |
| Precio estimado | $25.000 COP |

> El XH-M603 protege la batería contra sobrecargas y descarga profunda. Se conecta entre la salida del Boost y la entrada de la batería. Cuando la batería llega a 29.2 V (carga completa), el módulo corta la carga automáticamente.

### 4.5 Batería LiFePO4 24 V / 5 Ah + BMS

| Parámetro | Valor |
|---|---|
| Química | LiFePO4 (Litio Hierro Fosfato) |
| Configuración | 6S1P (6 celdas en serie, 3.2 V nominal c/u) |
| Tensión nominal | 22.2 V (≈ 24 V en uso) |
| Tensión de carga completa | 29.2 V (4.85 V/celda) |
| Tensión de corte | 18.0 V (3.0 V/celda) |
| Capacidad | 5 Ah → 110–120 Wh |
| Corriente de descarga continua | 10 A |
| Corriente de descarga pico | 20 A (< 5 s) |
| BMS integrado | 6S 15 A — protección: sobreVolt, subVolt, sobrecorriente, cortocircuito, sobretemperatura |
| Autonomía del sistema electrónico | > 4 horas @ consumo promedio ~25 W |
| Ciclos de vida | > 2000 ciclos @ 80% DOD |
| Peso | ~1.2 kg |
| Dimensiones aprox. | 145 × 60 × 35 mm |
| Referencia AliExpress | ítem 1005009963240184 |
| Precio estimado | $250.000 COP |
| Responsable compra | Santiago / Samuel |

> **Ventaja LiFePO4 sobre Li-Ion**: Mucho más segura en entornos de campo (sin riesgo de ignición espontánea), mayor estabilidad térmica (Tmax operación = 60°C vs 45°C de Li-Ion), mayor vida útil en ciclos.

> **Cálculo de autonomía**:
> - Embrague DLD6-05: ~4 A × 24 V = 96 W (solo cuando está acoplado; ciclo ~40%)
> - Sistema de control: ~0.5 A × 5 V = 2.5 W (continuo)
> - Pilotos LED 24 V (×3): ~0.3 A × 24 V = 7.2 W (continuo)
> - **Consumo promedio**: ~(96 × 0.4) + 2.5 + 7.2 ≈ **48 W**
> - Autonomía = 110 Wh ÷ 48 W ≈ **2.3 h solo con batería**
> - Con alternador funcionando (≥ 100 W), el balance energético es positivo → autonomía **ilimitada** en operación normal.

### 4.6 Convertidor Buck DC-DC (24 V → 5 V)

| Parámetro | Valor |
|---|---|
| Topología | Buck (reductor) con regulación PWM |
| Tensión de entrada | 8–36 V DC |
| Tensión de salida | 5.0 V DC ± 0.1 V |
| Corriente de salida | 3 A continua |
| Eficiencia | ≥ 85% @ carga nominal |
| CI recomendado | LM2596HVS o MP1584EN |
| Protecciones | Sobrecorriente, sobrevoltaje de salida |
| Cantidad | 2 unidades (una de respaldo) |
| Precio estimado | $12.000 COP c/u |

> Alimenta: PIC18F4550, HX711, LCD 20×4 I2C, teclado 4×4, buzzer, servo MG996R, lógica de señal.

### 4.7 Embrague Electromagnético DLD6-05 Tipo A (parte eléctrica)

| Parámetro | Valor |
|---|---|
| Tensión de operación | 24 VDC ± 10% |
| Corriente nominal | 3–4 A (absorción al energizar: hasta 6 A por 50 ms) |
| Potencia disipada | ~80–100 W |
| Resistencia de bobina | ~5–8 Ω @ 20°C |
| Protección | **Diodo flyback 1N4007 en anti-paralelo** (obligatorio) |
| Control | SSR 24VDC/10A (conmutación desde PIC18F4550) |
| Seguridad | E-Stop NC en serie con la línea de 24 V al SSR |

> **⚠️ CRÍTICO**: Sin el diodo flyback, la apertura del circuito genera un pico de tensión inductiva de hasta 5× la tensión nominal (≈120 V). Este pico destruye el SSR, el BMS y puede dañar la batería. El diodo 1N4007 debe soldarse **directamente** sobre los terminales del embrague, con la polaridad correcta (cátodo al positivo del embrague).

---

## 5. DIAGRAMA UNIFILAR DEL SISTEMA ELÉCTRICO

```mermaid
flowchart LR
    subgraph MOTOR_SIDE["Lado Motor (en campo)"]
        MOT["Motor\n6.5 HP"]
        ALT["Alternador\n100-200W\nAC trifásico"]
        RECT["Rectificador\n+ Regulador\n13.8-14.5V DC"]
        MOT -->|eje| ALT --> RECT
    end

    subgraph STORAGE["Almacenamiento"]
        BOOST["Boost DC-DC\n14V→29.2V\n5A"]
        XHM["XH-M603\nControl carga\nLiFePO4"]
        BAT["Batería LiFePO4\n24V / 5Ah\n+ BMS 6S"]
        RECT -->|14V DC| BOOST --> XHM --> BAT
    end

    subgraph PROTECTION["Protección Principal"]
        F_MAIN["Fusible\n15A / 32V"]
        ESTOP["E-Stop NC\nhongo Ø40mm\n24VDC / 10A"]
        BAT -->|24V DC| F_MAIN
    end

    subgraph LOADS_24["Cargas 24 V DC"]
        SSR_E["SSR\n24VDC/10A"]
        EMB_E["Embrague\nDLD6-05\n24V / 4A\n+ D flyback"]
        LED24["Pilotos LED\n24V × 3\nVerde/Amarillo/Rojo"]
        F_MAIN -->|"24V (vía E-Stop en línea SSR)"| SSR_E --> EMB_E
        F_MAIN -->|24V directo| LED24
    end

    subgraph LOADS_5["Cargas 5 V DC"]
        BUCK_E["Buck DC-DC\n24V→5V / 3A"]
        CTRL5["Sistema control\nPIC + HX711\nLCD + Teclado\nBuzzer + Servo"]
        F_MAIN -->|24V| BUCK_E --> CTRL5
    end
```

---

## 6. CABLEADO DE POTENCIA ENTRE MÓDULOS

### 6.1 Secciones de Cable Recomendadas

| Tramo | Corriente Máx. | Sección Recomendada | Tipo |
|---|---|---|----|
| Alternador → Rectificador | 15 A AC | 2.5 mm² (AWG 13) | Cable flexible THHN |
| Rectificador → Boost DC-DC | 10 A DC | 2.5 mm² (AWG 13) | Cable flexible DC |
| Boost → Batería (positivo) | 10 A DC | 2.5 mm² (AWG 13) | Cable flexible DC |
| Batería → Fusible principal | 15 A DC | 4.0 mm² (AWG 11) | Cable rígido DC |
| Bus 24V → SSR (embrague) | 6 A DC | 1.5 mm² (AWG 15) | Cable flexible |
| Bus 24V → Buck DC-DC | 3 A DC | 1.0 mm² (AWG 17) | Cable flexible |
| Bus 24V → Pilotos LED | 1 A DC | 0.75 mm² (AWG 18) | Cable flexible |
| Buck 5V → Módulo control | 3 A DC | 1.0 mm² (AWG 17) | Cable flexible |

> **Norma de colores** (seguir en TODO el proyecto):
> - Rojo / naranja: positivo 24 V DC
> - Amarillo: positivo 14 V DC (pre-Boost)
> - Negro: GND / masa común
> - Verde/amarillo: tierra de seguridad (chasis)
> - Azul: positivo 5 V DC (lógico)

### 6.2 Conectores entre Módulos

Todos los cables entre módulos usarán **conectores industriales con latch** (enclavamiento mecánico) para evitar desconexiones por vibración:

| Circuito | Conector Recomendado | Pines |
|---|---|----|
| 24 V DC principal (Mod1 → Mod3) | Anderson SB50 rojo | 2 pines (+ y GND) |
| 5 V DC lógico (Mod1 → Mod3) | JST-VH 3.96 mm | 2 pines |
| Señal SSR (Mod3 → embrague) | JST-XH 2.54 mm | 2 pines |
| Cable comunicación pilotos | Molex MX1.25 | 6 pines (3 × GND + señal) |

### 6.3 Protecciones

| Protección | Dispositivo | Dónde |
|---|---|---|
| Fusible principal | Fusible automotriz 15 A + portafusible | En positivo salida batería |
| Fusible derivación control | Fusible 3 A | Entrada buck DC-DC |
| Fusible derivación embrague | Fusible 8 A | Línea 24V al SSR |
| Flyback embrague | Diodo 1N4007 en anti-paralelo | Directamente en bornes embrague |
| E-Stop hardware | Pulsador NC Ø40mm 10A/24V | En serie con 24V al SSR |
| BMS batería | BMS 6S 15A integrado | Dentro del pack LiFePO4 |
| Corte por temperatura | Bimetal o sensor NTC en la caja | En la caja de control |

---

## 7. SISTEMA DE CARGA — ESTADOS Y TRANSICIONES

```mermaid
stateDiagram-v2
    [*] --> SIN_MOTOR : Sistema apagado

    SIN_MOTOR : SIN MOTOR\nSolo batería disponible\nCapacidad: 5 Ah → ~2.3h autonomía\nAlternador desconectado

    ARRANQUE : ARRANQUE MOTOR\n0 a 30 seg\nAlternador genera < 50W\nSistema en batería\nXH-M603: modo espera

    CARGA_ACTIVA : CARGA ACTIVA\nAlternador >= 100W\nBoost activo\nXH-M603 cargando\nBalance positivo\nSistema en operación

    CARGA_COMPLETA : BATERÍA COMPLETA\n100% SOC\nXH-M603 corta carga\nAlternador en flotación\nVoltaje: 29.2V

    SOLO_DESCARGA : SOLO DESCARGA\nMotor apagado\nSistema en batería\nXH-M603 monitorea\n< 18V → corte

    CORTE_BMS : CORTE BMS\nSubvoltaje detectado\nBMS desconecta cargas\nRequiere recarga

    SIN_MOTOR --> ARRANQUE : Encender motor
    ARRANQUE --> CARGA_ACTIVA : RPM estables / 30 seg
    CARGA_ACTIVA --> CARGA_COMPLETA : Voltaje = 29.2V
    CARGA_COMPLETA --> CARGA_ACTIVA : Voltaje cae < 28.5V
    CARGA_ACTIVA --> SOLO_DESCARGA : Apagar motor en operación
    SOLO_DESCARGA --> CORTE_BMS : Voltaje < 18V
    CORTE_BMS --> SIN_MOTOR : Recargar batería
```

---

## 8. MONTAJE FÍSICO — MÓDULO 1 (POTENCIA)

### 8.1 Disposición de Componentes

El Módulo 1 debe organizarse para maximizar la disipación de calor y minimizar la longitud de cables de alta corriente:

```
┌──────────────────────────────────────────────────┐
│              MÓDULO 1 — CAJA DE POTENCIA          │
│                                                   │
│  [MOTOR 6.5HP]  ═══ eje ═══ [ALTERNADOR]         │
│        │                         │                │
│        │                    [RECTIFICADOR]         │
│        │                    [REGULADOR]            │
│        │                         │  14V DC         │
│        └──────────────────  [BOOST DC-DC]         │
│                                  │  24-29V DC      │
│                             [XH-M603]             │
│                                  │                │
│                         [BATERÍA LiFePO4]         │
│                             + [BMS 6S]            │
│                                  │  24V DC         │
│                         [FUSIBLE PRINCIPAL]       │
│                                  │                │
│              ┌───────────────────┤                │
│              │                   │                │
│         [BUCK 5V]          [SALIDA 24V]           │
│              │  5V DC            │  24V DC         │
│         → Módulo 3          → Mod3 (SSR+EMB)     │
└──────────────────────────────────────────────────┘
```

### 8.2 Consideraciones de Seguridad en el Montaje

1. **Temperatura**: El rectificador y el Boost DC-DC generan calor. Montar sobre disipadores de aluminio con pasta térmica. Prever ventilación pasiva mínima o un pequeño ventilador DC 5V si la caja es cerrada.

2. **Acceso al fusible**: El portafusible principal debe ser accesible sin abrir la caja (montado en pared lateral o con tapa transparente).

3. **Motor y alternador**: Ubicar con escape del motor **alejado** de la zona de arroz procesado. El cable del alternador al rectificador debe ir por canaleta separada de los cables DC.

4. **Batería**: Montar en posición fija con cinta de doble faz + sujetador de velcro. La batería LiFePO4 no requiere ventilación especial (no emite gases en operación normal).

5. **Separación de masas**: La GND del sistema eléctrico (24 V) y la GND del sistema lógico (5 V) se unen en UN SOLO PUNTO (punto de estrella) dentro del Módulo 3. Ver `08_Electronica/GUIA_ELECTRONICA.md §13`.

---

## 9. PRUEBAS DE VALIDACIÓN DEL SISTEMA ELÉCTRICO

| ID | Prueba | Procedimiento | Criterio de éxito |
|----|---|---|---|
| E1 | Tensión de salida alternador | Arrancar motor, medir Vout del rectificador | 13.5–14.8 V DC @ 3600 RPM |
| E2 | Funcionamiento Boost DC-DC | Verificar salida del Boost con motor en marcha | 28.8–29.5 V DC @ carga 3 A |
| E3 | Carga de batería | Dejar cargando 30 min con motor, medir voltaje batería | Incremento > 0.5 V / 15 min |
| E4 | Estabilidad del Buck 5 V | Con sistema en operación, medir V5V con carga y sin carga | 4.9–5.1 V DC bajo cualquier condición |
| E5 | Consumo del embrague | Medir corriente con embrague acoplado | < 5 A @ 24 V DC |
| E6 | Autonomía de batería | Apagar motor, operar solo con batería, medir tiempo hasta corte BMS | ≥ 2 horas de operación |
| E7 | E-Stop hardware | Presionar E-Stop durante operación normal con embrague acoplado | Embrague desacoplado en < 0.5 s |
| E8 | Diodo flyback | Con osciloscopio, medir pico de voltaje al abrir embrague | Pico < 30 V (sin flyback puede llegar a 100 V+) |
| E9 | BMS protección | Desconectar cable positivo de batería en operación | Sin chispa en bornes del BMS |
| E10 | Temperatura 1 hora | Operar 1 hora continua, medir temperatura componentes | T < 70°C en todos los componentes |

---

## 10. LISTA DE MATERIALES — SISTEMA ELÉCTRICO

| N° | Componente | Cant. | Especificación | Precio Unit. COP | Total COP | Estado | Resp. |
|----|---|---|---|---|---|---|---|
| E1 | Alternador de motocicleta | 1 | 100–200 W AC trifásico, 14 V rectificado | $180.000 | $180.000 | 🛒 Por adquirir | Santiago / Samuel |
| E2 | Rectificador + regulador 14 V | 1 | Puente diodos 15 A + regulador moto | $35.000 | $35.000 | 🛒 Por adquirir | Santiago |
| E3 | Boost DC-DC 14 V → 24 V | 1 | 5 A, η ≥ 85%, step-up XL6009 | $45.000 | $45.000 | 🛒 Por adquirir | Samuel |
| E4 | Batería LiFePO4 24 V / 5 Ah | 1 | 6S1P, BMS 6S 15 A integrado | $250.000 | $250.000 | 📋 Cotizado | Santiago / Samuel |
| E5 | Módulo carga XH-M603 | 1 | Control carga baterías litio | $25.000 | $25.000 | 🛒 Por adquirir | Samuel |
| E6 | Buck DC-DC 24 V → 5 V / 3 A | 2 | LM2596 o MP1584 | $12.000 | $24.000 | 🛒 Por adquirir | Samuel |
| E7 | Fusible automotriz 15 A + portafusible | 2 | 32 V, tipo ATO con portafusible | $5.000 | $10.000 | 🛒 Por adquirir | Samuel |
| E8 | Fusible automotriz 8 A + portafusible | 2 | 32 V, protección derivación embrague | $4.000 | $8.000 | 🛒 Por adquirir | Samuel |
| E9 | Fusible automotriz 3 A + portafusible | 2 | 32 V, protección derivación control | $4.000 | $8.000 | 🛒 Por adquirir | Samuel |
| E10 | E-Stop hongo Ø40 mm NC | 1 | 10 A, 24 VDC, rojo, enclavado | $25.000 | $25.000 | 🛒 Por adquirir | Samuel |
| E11 | Conector Anderson SB50 rojo | 2 pares | 50 A, 600 V, par M/H | $18.000 | $36.000 | 🛒 Por adquirir | Samuel |
| E12 | Conectores JST-VH 3.96 mm | 5 pares | 2 pines, 10 A | $3.000 | $15.000 | 🛒 Por adquirir | Samuel |
| E13 | Cable flexible 2.5 mm² rojo (5 m) | 1 | THHN 600 V | $15.000 | $15.000 | 🛒 Por adquirir | Santiago |
| E14 | Cable flexible 2.5 mm² negro (5 m) | 1 | THHN 600 V | $15.000 | $15.000 | 🛒 Por adquirir | Santiago |
| E15 | Cable flexible 1.0 mm² azul (3 m) | 1 | THHN 600 V | $8.000 | $8.000 | 🛒 Por adquirir | Santiago |
| E16 | Diodo 1N4007 (×5) | 5 | 1 A, 1000 V, flyback y protección | $1.000 | $5.000 | 🛒 Por adquirir | Samuel |
| E17 | Disipadores de aluminio | 3 | Para rectificador, Boost y Buck | $5.000 | $15.000 | 🛒 Por adquirir | Santiago |
| E18 | Canaleta plástica 20×10 mm (2 m) | 2 | Para cableado interno módulo 1 | $8.000 | $16.000 | 🛒 Por adquirir | Santiago |
| E19 | Caja de paso IP54 (potencia) | 1 | Para alojar rectificador, boost, buck, módulo carga | $35.000 | $35.000 | 🛒 Por adquirir | Santiago |
| | **SUBTOTAL SISTEMA ELÉCTRICO** | | | | **$535.000** | | |

---

## 11. REFERENCIA RÁPIDA — PARÁMETROS ELÉCTRICOS CLAVE

| Parámetro | Valor |
|---|---|
| Tensión bus principal | 24 V DC (LiFePO4) |
| Tensión lógica | 5 V DC (buck) |
| Tensión de carga batería | 29.2 V (XH-M603) |
| Tensión de corte batería | 18.0 V (BMS) |
| Corriente max. embrague | 5 A @ 24 V |
| Corriente max. sistema control | 0.5 A @ 5 V |
| Corriente max. pilotos LED | 0.3 A @ 24 V |
| Corriente total (peak) | ~8 A @ 24 V |
| Potencia alternador | 100–200 W AC |
| Autonomía (solo batería) | ~2.3 h @ consumo promedio |
| Autonomía (con motor) | Ilimitada (balance positivo) |
| Norma cableado | Colores: rojo=24V, negro=GND, azul=5V |
| Fusible principal | 15 A / 32 V |

---

*Guía Eléctrica v1.0 | Abril 2026 | DAMSPI-150 — PAI 2017275 — Grupo B*
*Responsable: Santiago Ávila C. (diseño eléctrico) | Samuel D. Sánchez C. (compras)*

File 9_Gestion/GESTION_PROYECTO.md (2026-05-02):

# GESTIÓN DEL PROYECTO — DAMSPI-150
## EDT Detallado · Gantt · Gestión de Proveedores y Compras
### Responsable de Gestión: Samuel D. Sánchez C.

---

## 1. RESUMEN DE GESTIÓN

| Parámetro | Valor |
|---|---|
| Proyecto | DAMSPI-150 — Descascaradora de Arroz Modular Semiautomática con Pesaje Integrado |
| Duración total | 14 semanas (3 Feb – 30 May 2026) |
| Presupuesto disponible | $7.000.000 COP (aportado por solicitante) |
| Presupuesto estimado actual | ~$5.980.000 COP |
| Margen de contingencia | ~$1.020.000 COP (~14.6%) |
| Responsable de gestión | Samuel D. Sánchez C. |
| Método de seguimiento | Reunión semanal + actualización GANTT + bitácoras |
| Herramientas de gestión | Excel (GANTT + BOM) + GitHub/Drive (repositorio) |

---

## 2. ESTRUCTURA DE DESGLOSE DE TRABAJO (EDT / WBS)

### Nivel 1 — DAMSPI-150

```
DAMSPI-150
├── 1. GESTIÓN DEL PROYECTO
├── 2. INGENIERÍA DE SISTEMAS Y REQUISITOS
├── 3. DISEÑO MECÁNICO
│   ├── 3.1 Módulo 1 — Potencia y Transmisión
│   ├── 3.2 Módulo 2 — Descascarillado
│   ├── 3.3 Módulo 3 — Control y Pesaje (chasis)
│   └── 3.4 Módulo 4 — Chasis Principal y Tolvas
├── 4. DISEÑO ELÉCTRICO (POTENCIA)
├── 5. DISEÑO ELECTRÓNICO (CONTROL)
├── 6. ADQUISICIONES Y MANUFACTURA
│   ├── 6.1 Gestión de proveedores
│   ├── 6.2 Compras y tiempos de espera
│   └── 6.3 Manufactura aditiva y taller externo
├── 7. MONTAJE E INTEGRACIÓN
├── 8. VALIDACIÓN Y PRUEBAS
└── 9. DOCUMENTACIÓN Y ENTREGA FINAL
```

---

### EDT COMPLETO — Nivel 3 (todas las tareas)

#### 1. GESTIÓN DEL PROYECTO

| ID | Tarea | Responsable | Semana Inicio | Semana Fin | Duración |
|----|---|---|---|---|---|
| 1.1 | Reunión de lanzamiento y definición de roles | Todos | S1 | S1 | 1 sem |
| 1.2 | Configuración del repositorio (Drive + estructura) | Samuel | S1 | S1 | 0.5 sem |
| 1.3 | Elaboración del acuerdo con solicitante (AS) | Todos | S1 | S2 | 1 sem |
| 1.4 | Elaboración del contrato social (CS) | Todos | S1 | S2 | 1 sem |
| 1.5 | Definición del presupuesto inicial y BOM v0 | Samuel | S2 | S2 | 0.5 sem |
| 1.6 | Reunión semanal de seguimiento | Todos | S1 | S14 | 14 sem |
| 1.7 | Actualización semanal del GANTT | Samuel | S1 | S14 | 14 sem |
| 1.8 | Actualización semanal de bitácoras individuales | Todos | S1 | S14 | 14 sem |
| 1.9 | Actualización del registro de proveedores | Samuel | S3 | S12 | 10 sem |
| 1.10 | Control de presupuesto vs. gasto real | Samuel | S3 | S14 | 12 sem |
| 1.11 | Revisión de riesgos y plan de contingencia | Samuel | S4 | S4 | 1 sem |
| 1.12 | Comunicación con solicitante (actualizaciones) | Samuel | S4 | S13 | 10 sem |

#### 2. INGENIERÍA DE SISTEMAS Y REQUISITOS

| ID | Tarea | Responsable | Semana Inicio | Semana Fin | Duración |
|----|---|---|---|---|---|
| 2.1 | Revisión bibliográfica y estado del arte | Todos | S1 | S3 | 3 sem |
| 2.2 | Definición de requerimientos técnicos (PDS) | Nicolás + Samuel | S2 | S3 | 2 sem |
| 2.3 | Definición de restricciones y normas aplicables | Nicolás + Samuel | S2 | S3 | 1 sem |
| 2.4 | Diseño de la arquitectura de módulos | Nicolás | S3 | S4 | 2 sem |
| 2.5 | Diagramas de caja negra y caja gris | Nicolás + Gabriel | S3 | S5 | 3 sem |
| 2.6 | Análisis funcional del sistema (QFD simplificado) | Nicolás + Samuel | S4 | S5 | 2 sem |
| 2.7 | Redacción del Informe Parte I | Todos | S3 | S4 | 2 sem |
| 2.8 | Entrega y sustentación Informe Parte I | Todos | S4 | S4 | 0.5 sem |

#### 3. DISEÑO MECÁNICO

##### 3.1 Módulo 1 — Potencia y Transmisión

| ID | Tarea | Responsable | Semana Inicio | Semana Fin | Duración |
|----|---|---|---|---|---|
| 3.1.1 | Selección de tipo de transmisión (poleas en V) | Nicolás | S3 | S4 | 2 sem |
| 3.1.2 | Cálculo de relación de transmisión y dimensionado poleas | Nicolás | S4 | S5 | 2 sem |
| 3.1.3 | Selección del eje secundario: material, diámetros, longitud | Sebastián | S4 | S6 | 3 sem |
| 3.1.4 | Cálculo de rodamientos para eje secundario | Sebastián | S5 | S6 | 2 sem |
| 3.1.5 | Diseño del soporte del alternador (optimización topológica) | Andrés | S5 | S7 | 3 sem |
| 3.1.6 | Diseño de la carcasa del Módulo 1 (CAD Onshape) | Andrés | S6 | S8 | 3 sem |
| 3.1.7 | Diseño del sistema de acoplamiento embrague-eje | Nicolás + Sebastián | S5 | S7 | 3 sem |
| 3.1.8 | Planos de fabricación Módulo 1 | Nicolás | S8 | S9 | 2 sem |

##### 3.2 Módulo 2 — Descascarillado

| ID | Tarea | Responsable | Semana Inicio | Semana Fin | Duración |
|----|---|---|---|---|---|
| 3.2.1 | Investigación de parámetros de rodillos PU (Solagro) | Nicolás | S3 | S5 | 3 sem |
| 3.2.2 | Cálculo de fuerzas de descascarillado (presión rodillos) | Nicolás | S5 | S6 | 2 sem |
| 3.2.3 | Diseño del sistema de ajuste de la separación entre rodillos | Nicolás | S5 | S7 | 3 sem |
| 3.2.4 | Diseño del ventilador centrífugo para separación cáscara | Andrés | S6 | S8 | 3 sem |
| 3.2.5 | Diseño del Sin Fín alimentador (o compuerta de gaveta) | Sebastián | S6 | S8 | 3 sem |
| 3.2.6 | Diseño de la tolva de entrada y compuerta servomotor | Andrés | S6 | S8 | 3 sem |
| 3.2.7 | CAD Onshape Módulo 2 completo | Andrés + Nicolás | S7 | S9 | 3 sem |
| 3.2.8 | Planos de fabricación Módulo 2 | Nicolás | S9 | S10 | 2 sem |

##### 3.3 Módulo 3 — Carcasa del Panel de Control

| ID | Tarea | Responsable | Semana Inicio | Semana Fin | Duración |
|----|---|---|---|---|---|
| 3.3.1 | Diseño de la carcasa del panel LCD + teclado + pilotos | Andrés | S7 | S8 | 2 sem |
| 3.3.2 | Soporte plataforma de pesaje (celdas tipo S) | Andrés | S7 | S8 | 2 sem |
| 3.3.3 | Optimización topológica soportes celdas + plataforma | Andrés | S6 | S8 | 3 sem |
| 3.3.4 | Diseño de puntos de conexión rápida (Módulo 3 ↔ 4) | Nicolás | S8 | S9 | 2 sem |
| 3.3.5 | CAD Onshape Módulo 3 (carcasa) | Andrés | S8 | S9 | 2 sem |

##### 3.4 Módulo 4 — Chasis Principal

| ID | Tarea | Responsable | Semana Inicio | Semana Fin | Duración |
|----|---|---|---|---|---|
| 3.4.1 | Diseño estructural del chasis (perfiles 40×40 mm) | Nicolás | S5 | S7 | 3 sem |
| 3.4.2 | Cálculo de cargas sobre el chasis (FEM simplificado) | Sebastián | S6 | S7 | 2 sem |
| 3.4.3 | Diseño del sistema de ruedas + bloqueo | Andrés | S7 | S8 | 2 sem |
| 3.4.4 | Diseño de los pasadores de conexión rápida entre módulos | Nicolás | S7 | S8 | 2 sem |
| 3.4.5 | CAD Onshape Módulo 4 completo | Nicolás + Andrés | S7 | S9 | 3 sem |
| 3.4.6 | Planos de fabricación Módulo 4 | Nicolás | S9 | S10 | 2 sem |

#### 4. DISEÑO ELÉCTRICO (POTENCIA)

| ID | Tarea | Responsable | Semana Inicio | Semana Fin | Duración |
|----|---|---|---|---|---|
| 4.1 | Cálculo de potencia eléctrica requerida total | Santiago | S4 | S4 | 1 sem |
| 4.2 | Selección del alternador: tipo, potencia, acoplamiento | Santiago | S4 | S5 | 2 sem |
| 4.3 | Diseño circuito rectificador + regulador | Santiago | S5 | S6 | 2 sem |
| 4.4 | Diseño circuito Boost DC-DC (14V→24V) | Santiago | S5 | S6 | 2 sem |
| 4.5 | Diseño circuito Buck DC-DC (24V→5V) | Santiago + Samuel | S5 | S6 | 2 sem |
| 4.6 | Diseño del sistema de carga de batería (XH-M603) | Santiago | S6 | S7 | 2 sem |
| 4.7 | Dimensionado de cables y secciones por tramo | Santiago | S7 | S8 | 2 sem |
| 4.8 | Diseño del cableado de potencia entre módulos | Santiago | S8 | S9 | 2 sem |
| 4.9 | Diseño del circuito de protecciones (fusibles, E-Stop) | Santiago + Samuel | S7 | S8 | 2 sem |
| 4.10 | Documentación guía eléctrica v1.0 | Santiago | S8 | S9 | 2 sem |

#### 5. DISEÑO ELECTRÓNICO (CONTROL)

| ID | Tarea | Responsable | Semana Inicio | Semana Fin | Duración |
|----|---|---|---|---|---|
| 5.1 | Definición de la arquitectura de control | Samuel + Gabriel | S4 | S4 | 1 sem |
| 5.2 | Asignación de pines PIC18F4550 | Samuel | S4 | S5 | 1 sem |
| 5.3 | Diseño esquemático completo (Módulo 3) | Gabriel | S5 | S7 | 3 sem |
| 5.4 | Diseño del circuito de interfaz SSR + embrague | Gabriel | S5 | S6 | 2 sem |
| 5.5 | Diseño del circuito de pilotos LED (drivers 2N2222) | Gabriel | S5 | S6 | 1 sem |
| 5.6 | Diseño circuito de celdas de carga (puente Wheatstone → HX711) | Samuel | S5 | S6 | 2 sem |
| 5.7 | Diseño circuito LCD 20×4 I2C (PCF8574) | Gabriel | S5 | S6 | 1 sem |
| 5.8 | Diseño circuito teclado matricial 4×4 (PORTB) | Gabriel | S5 | S6 | 1 sem |
| 5.9 | Revisión y validación del esquemático | Samuel + Gabriel | S7 | S7 | 1 sem |
| 5.10 | Firmware: initPorts(), initInterrupts(), initLCD_I2C() | Samuel | S6 | S7 | 2 sem |
| 5.11 | Firmware: driver HX711 (hx711_leer_raw, promedio, tara) | Samuel | S7 | S8 | 2 sem |
| 5.12 | Firmware: driver LCD I2C y teclado matricial | Samuel | S7 | S8 | 2 sem |
| 5.13 | Firmware: máquina de estados principal (FSM) | Samuel | S8 | S9 | 2 sem |
| 5.14 | Firmware: control SSR embrague + servo MG996R | Samuel | S8 | S9 | 2 sem |
| 5.15 | Firmware: EEPROM — guardar/restaurar calibración | Samuel | S9 | S9 | 1 sem |
| 5.16 | Firmware: alertas (buzzer, pilotos LED) | Samuel | S9 | S10 | 1 sem |
| 5.17 | Firmware: E-Stop hardware y software | Samuel + Gabriel | S9 | S10 | 1 sem |
| 5.18 | Prueba de firmware en banco (sin mecánica) | Samuel + Gabriel | S10 | S10 | 1 sem |
| 5.19 | Documentación guía electrónica v2.0 | Samuel | S8 | S10 | 3 sem |

#### 6. ADQUISICIONES Y MANUFACTURA

##### 6.1 Gestión de Proveedores (SAMUEL — responsable único)

| ID | Tarea | Responsable | Semana Inicio | Semana Fin | Duración |
|----|---|---|---|---|---|
| 6.1.1 | Contacto inicial con Solagro Colombia (rodillos, pulidora) | Samuel | S3 | S3 | 0.5 sem |
| 6.1.2 | Solicitud de cotización formal a Solagro (rodillos PU Ø80mm + pulidora horizontal) | Samuel | S3 | S4 | 1 sem |
| 6.1.3 | Contacto y cotización: embrague DLD6-05 (MercadoLibre / proveedor local) | Samuel | S3 | S4 | 1 sem |
| 6.1.4 | Contacto y cotización: batería LiFePO4 24V 5Ah (AliExpress + alternativa local) | Samuel | S3 | S4 | 1 sem |
| 6.1.5 | Cotización: alternador de motocicleta (repuestos motos Bogotá + MercadoLibre) | Samuel | S4 | S4 | 0.5 sem |
| 6.1.6 | Cotización: perfiles acero 40×40 + rodamientos + poleas (ferretería industrial) | Samuel | S4 | S5 | 1 sem |
| 6.1.7 | Contacto taller externo UNAL para mecanizado ejes | Samuel + Nicolás | S4 | S5 | 1 sem |
| 6.1.8 | Cotización: PCB fabricada (JLCPCB/PCBWay o local) | Gabriel + Samuel | S6 | S7 | 2 sem |
| 6.1.9 | Cotización: PIC18F4550 + HX711 + LCD 20×4 I2C (AliExpress, Naylampmechatronics) | Samuel | S4 | S5 | 1 sem |
| 6.1.10 | Cotización: SSR 24VDC, servo MG996R, pilotos industriales, E-Stop | Samuel | S4 | S5 | 1 sem |
| 6.1.11 | Comparación de cotizaciones y selección de proveedores definitivos | Samuel | S5 | S5 | 0.5 sem |
| 6.1.12 | Aprobación de compras con el equipo (reunión de compras) | Samuel + Todos | S5 | S5 | 0.5 sem |
| 6.1.13 | Registro y actualización del REGISTRO_PROVEEDORES.md | Samuel | S3 | S14 | Continuo |
| 6.1.14 | Seguimiento semanal a pedidos pendientes | Samuel | S5 | S11 | 7 sem |
| 6.1.15 | Recepción e inspección de componentes (verificar contra BOM) | Samuel | S6 | S12 | Continuo |
| 6.1.16 | Informe semanal de compras al equipo (WhatsApp/Discord) | Samuel | S5 | S12 | 8 sem |

##### 6.2 Compras y Tiempos de Espera (SAMUEL)

| ID | Componente | Semana Pedido | Tiempo Espera Est. | Semana Llegada | Estado |
|----|---|---|---|---|---|
| 6.2.1 | Rodillos PU Ø80mm + pulidora (Solagro) | S4 | 3–4 semanas | S7–S8 | Gestionar S3 |
| 6.2.2 | Batería LiFePO4 24V/5Ah (AliExpress) | S4 | 4–6 semanas | S8–S10 | ⚠️ Urgente |
| 6.2.3 | Embrague DLD6-05 24V (local/MercadoLibre) | S4 | 1–2 semanas | S5–S6 | — |
| 6.2.4 | PIC18F4550, HX711, LCD 20×4 I2C (AliExpress) | S4 | 3–5 semanas | S7–S9 | ⚠️ Urgente |
| 6.2.5 | Teclado matricial 4×4, SSR, servo MG996R (local) | S5 | 1–2 semanas | S6–S7 | — |
| 6.2.6 | Alternador de motocicleta (local Bogotá) | S5 | 1 semana | S6 | — |
| 6.2.7 | Celda de carga tipo S ×4 (AliExpress) | S4 | 3–5 semanas | S7–S9 | ⚠️ Urgente |
| 6.2.8 | Perfiles acero + poleas + rodamientos (local) | S6 | 1 semana | S7 | — |
| 6.2.9 | Componentes electrónicos locales (resistencias, condensadores, transistores) | S5 | 1–3 días | S5 | — |
| 6.2.10 | PCB fabricada (JLCPCB — envío express) | S8 | 1–2 semanas | S9–S10 | Requiere esquemático S7 |
| 6.2.11 | Caja de control IP54 + prensaestopas | S6 | 1 semana | S7 | — |
| 6.2.12 | Cable eléctrico + conectores industriales | S6 | 1–3 días | S6 | — |
| 6.2.13 | Impresión 3D piezas PETG/PLA+ (taller externo o campus) | S9 | 1–2 semanas | S10–S11 | Requiere CAD S8 |

> **⚠️ ALERTA DE RUTA CRÍTICA**: Los ítems 6.2.1 (rodillos Solagro), 6.2.2 (batería AliExpress), 6.2.4 (PIC+HX711+LCD) y 6.2.7 (celdas de carga) tienen los tiempos de espera más largos. Samuel debe iniciar la gestión de estos en la **Semana 3** para garantizar disponibilidad en Semana 8–9 (inicio de montaje).

##### 6.3 Manufactura — Piezas Impresas y Taller Externo

| ID | Tarea | Responsable | Semana Inicio | Semana Fin | Duración |
|----|---|---|---|---|---|
| 6.3.1 | Optimización topológica soportes celdas de carga | Andrés | S6 | S8 | 3 sem |
| 6.3.2 | Optimización topológica soporte alternador | Andrés | S6 | S7 | 2 sem |
| 6.3.3 | Preparación archivos STL para impresión 3D (todos los módulos) | Andrés | S9 | S9 | 1 sem |
| 6.3.4 | Gestión de impresión 3D en campus o taller externo | Andrés + Samuel | S9 | S10 | 2 sem |
| 6.3.5 | Post-procesado de piezas impresas (insertos calor, lijado) | Andrés | S10 | S11 | 2 sem |
| 6.3.6 | Coordinación taller externo para mecanizado eje secundario | Nicolás + Samuel | S6 | S8 | 3 sem |
| 6.3.7 | Mecanizado de ejes, chavetas, rosca (taller externo UNAL) | Taller externo | S8 | S9 | 2 sem |
| 6.3.8 | Soldadura del chasis (taller externo) | Taller externo | S9 | S10 | 2 sem |
| 6.3.9 | Limpieza y pintura del chasis | Andrés + Sebastián | S10 | S11 | 1 sem |

#### 7. MONTAJE E INTEGRACIÓN

| ID | Tarea | Responsable | Semana Inicio | Semana Fin | Duración |
|----|---|---|---|---|---|
| 7.1 | Ensamble Módulo 1 (motor + alternador + transmisión) | Nicolás + Santiago | S10 | S11 | 2 sem |
| 7.2 | Ensamble Módulo 2 (rodillos + ventilador + Sin Fín) | Nicolás + Sebastián | S10 | S11 | 2 sem |
| 7.3 | Ensamble Módulo 3 — Electrónica (PCB + sensores + panel) | Samuel + Gabriel | S10 | S11 | 2 sem |
| 7.4 | Instalación del sistema de pesaje (celdas + HX711 + plataforma) | Samuel | S11 | S11 | 1 sem |
| 7.5 | Cableado eléctrico de potencia entre módulos | Santiago + Samuel | S11 | S12 | 2 sem |
| 7.6 | Instalación del embrague + SSR + cableado 24V | Samuel + Santiago | S11 | S11 | 1 sem |
| 7.7 | Ensamble Módulo 4 (chasis + ruedas + pasadores) | Nicolás + Andrés | S10 | S11 | 2 sem |
| 7.8 | Integración de los 4 módulos sobre el chasis | Todos | S11 | S12 | 2 sem |
| 7.9 | Primera puesta en marcha (sin arroz) | Todos | S12 | S12 | 1 sem |
| 7.10 | Ajuste de rodillos y calibración mecánica | Nicolás + Sebastián | S12 | S12 | 1 sem |

#### 8. VALIDACIÓN Y PRUEBAS

| ID | Prueba | Responsable | Semana Inicio | Semana Fin | Duración |
|----|---|---|---|---|---|
| 8.1 | P1: Calibración sistema de pesaje (HX711 + celdas) | Samuel | S12 | S12 | 1 sem |
| 8.2 | P2: Prueba de tara dinámica con motor encendido | Samuel | S12 | S12 | 0.5 sem |
| 8.3 | P3: Prueba de paro automático por peso objetivo | Samuel + Gabriel | S12 | S12 | 0.5 sem |
| 8.4 | P4: Prueba E-Stop hardware | Samuel + Santiago | S12 | S12 | 0.5 sem |
| 8.5 | P5: Autonomía de la batería | Santiago | S12 | S13 | 1 sem |
| 8.6 | P6: Eficiencia de descascarillado (% granos rotos) | Nicolás + Sebastián | S12 | S13 | 2 sem |
| 8.7 | P7: Medición de capacidad (kg/h real) | Todos | S13 | S13 | 1 sem |
| 8.8 | P8: Ruido (dB) y vibración | Nicolás + Sebastián | S13 | S13 | 0.5 sem |
| 8.9 | P9: Prueba de desmontaje/montaje completo (≤ 60 min) | Todos | S13 | S13 | 0.5 sem |
| 8.10 | P10: Temperatura PCB y componentes eléctricos (1h continua) | Samuel + Santiago | S13 | S13 | 1 sem |
| 8.11 | Registro de resultados y análisis de desviaciones | Samuel + Nicolás | S13 | S13 | 1 sem |
| 8.12 | Correcciones post-prueba (ajustes mecánicos + firmware) | Todos | S13 | S13 | 1 sem |
| 8.13 | Grabación del video de demostración | Todos | S13 | S13 | 0.5 sem |

#### 9. DOCUMENTACIÓN Y ENTREGA FINAL

| ID | Tarea | Responsable | Semana Inicio | Semana Fin | Duración |
|----|---|---|---|---|---|
| 9.1 | Redacción Informe Parte II (diseño detallado) | Todos | S6 | S8 | 3 sem |
| 9.2 | Entrega y sustentación Informe Parte II | Todos | S8 | S8 | 0.5 sem |
| 9.3 | Redacción Informe Final Parte III | Todos | S12 | S14 | 3 sem |
| 9.4 | Planos de fabricación finales (PDF/DWG) | Nicolás | S10 | S12 | 3 sem |
| 9.5 | Manual de usuario del DAMSPI-150 | Samuel + Nicolás | S13 | S14 | 2 sem |
| 9.6 | Manual de mantenimiento preventivo | Santiago + Nicolás | S13 | S14 | 2 sem |
| 9.7 | Actualización BOM final con precios reales | Samuel | S13 | S14 | 1 sem |
| 9.8 | Preparación de la presentación final | Todos | S13 | S14 | 2 sem |
| 9.9 | Entrega final y demostración al solicitante | Todos | S14 | S14 | 1 día |
| 9.10 | Cierre del repositorio y archivo definitivo | Samuel | S14 | S14 | 0.5 sem |

---

## 3. GANTT — CRONOGRAMA GENERAL (Semanas 1–14)

> **Referencia**: El archivo Excel `03_Cronograma_GANTT/GANTT_Descascaradora_v2.xlsx` contiene el GANTT original. La versión actualizada refleja el EDT completo de la sección 2.

```
TAREA / FASE                          S1  S2  S3  S4  S5  S6  S7  S8  S9 S10 S11 S12 S13 S14
─────────────────────────────────────────────────────────────────────────────────────────────
1. GESTIÓN DEL PROYECTO
  1.1 Reunión semanal                  ██  ██  ██  ██  ██  ██  ██  ██  ██  ██  ██  ██  ██  ██
  1.7 Actualización GANTT + BOM        ██  ██  ██  ██  ██  ██  ██  ██  ██  ██  ██  ██  ██  ██
  1.8 Bitácoras individuales           ██  ██  ██  ██  ██  ██  ██  ██  ██  ██  ██  ██  ██  ██

2. REQUISITOS Y SISTEMAS
  2.1 Revisión bibliográfica           ██  ██  ██
  2.2-2.6 Req. + arquitectura             ██  ██  ██  ██
  2.7-2.8 INFORME PARTE I                     ██  ██★

3.1 MÓDULO 1 MECÁNICO
  3.1.1-3.1.2 Transmisión                     ██  ██  ██
  3.1.3-3.1.4 Eje secundario                  ██  ██  ██  ██
  3.1.5-3.1.7 Soporte alt.+embrague               ██  ██  ██  ██
  3.1.6-3.1.8 CAD + planos                            ██  ██  ██  ██

3.2 MÓDULO 2 MECÁNICO
  3.2.1-3.2.2 Rodillos PU                     ██  ██  ██
  3.2.3-3.2.6 Ajustador+ventilador+Sin Fín        ██  ██  ██  ██
  3.2.7-3.2.8 CAD + planos                                ██  ██  ██

3.3-3.4 MÓDULOS 3-4 MECÁNICO
  Carcasa panel + soporte celdas                       ██  ██  ██
  Chasis + pasadores + ruedas                  ██  ██  ██  ██
  CAD Onshape + planos                                 ██  ██  ██

4. DISEÑO ELÉCTRICO (POTENCIA)
  4.1-4.5 Alternador+Boost+Buck                ██  ██  ██  ██
  4.6-4.9 Batería+XH-M603+cables                   ██  ██  ██  ██
  4.10 Guía eléctrica v1.0                                ██  ██

5. DISEÑO ELECTRÓNICO (CONTROL)
  5.1-5.2 Arquitectura + pines                 ██
  5.3-5.9 Esquemático completo                     ██  ██  ██  ██
  5.10-5.12 Firmware base (init+LCD+HX711)         ██  ██  ██
  5.13-5.17 Firmware FSM + control                     ██  ██  ██
  5.18 Prueba firmware en banco                            ██
  5.19 Guía electrónica v2.0                       ██  ██  ██

6. ADQUISICIONES Y MANUFACTURA
  6.1.1-6.1.5 Contacto Solagro+proveed.       ██  ██
  6.1.6-6.1.10 Cotizaciones electrónica        ██  ██
  6.1.11-6.1.12 Selección + aprobación             ██
  ⚠️ PEDIDO RODILLOS SOLAGRO                   ██  (entrega S7-S8)
  ⚠️ PEDIDO BATERÍA ALIEXPRESS                  ██  (entrega S8-S10)
  ⚠️ PEDIDO CELDAS DE CARGA                     ██  (entrega S7-S9)
  ⚠️ PEDIDO PIC+HX711+LCD I2C                   ██  (entrega S7-S9)
  Pedidos locales (electrónica general)            ██  ██
  Pedidos eléctricos (cables, conectores)          ██  ██
  6.1.14-6.1.16 Seguimiento pedidos                ██  ██  ██  ██  ██  ██  ██
  6.1.15 Recepción e inspección comp.               ██  ██  ██  ██  ██  ██
  6.3.1-6.3.5 Manufactura aditiva FDM                              ██  ██  ██
  6.3.6-6.3.9 Taller externo (ejes+chasis)                  ██  ██  ██  ██

7. MONTAJE E INTEGRACIÓN
  7.1-7.2 Ensamble Módulos 1 y 2                                       ██  ██
  7.3-7.6 Electrónica + cableado                                       ██  ██
  7.7-7.8 Chasis + integración 4 módulos                               ██  ██
  7.9-7.10 Primera puesta en marcha                                        ██

8. VALIDACIÓN Y PRUEBAS
  8.1-8.6 Pruebas de pesaje+E-Stop                                         ██  ██
  8.7-8.13 Pruebas mecánicas+video                                              ██

9. DOCUMENTACIÓN Y ENTREGA
  9.1-9.2 INFORME PARTE II                                 ██  ██★
  9.3-9.8 Informe Final + manual + video                                   ██  ██  ██
  9.9 ENTREGA FINAL                                                              ██★
─────────────────────────────────────────────────────────────────────────────────────────────
★ = Hito / Entregable clave       ⚠️ = Ítem en ruta crítica (no puede retrasarse)
```

### Hitos Críticos del Proyecto

| Hito | Semana | Descripción |
|---|---|---|
| M1 | S4 | Entrega y aprobación Informe Parte I |
| M2 | S4 | Todos los pedidos de largo plazo realizados (AliExpress) |
| M3 | S5 | Cotizaciones Solagro confirmadas + decisión de compra |
| M4 | S7–S8 | Llegada de componentes críticos (celdas, PIC, LCD, rodillos) |
| M5 | S8 | Entrega Informe Parte II — Diseño detallado completo |
| M6 | S9–S10 | Todos los componentes disponibles para montaje |
| M7 | S12 | Sistema ensamblado + primera puesta en marcha |
| M8 | S13 | Pruebas de validación completas + video grabado |
| M9 | S14 | Entrega final al solicitante |

---

## 4. GESTIÓN DE RIESGOS

| ID | Riesgo | Probabilidad | Impacto | Estrategia de Mitigación | Responsable |
|----|---|---|---|---|---|
| R1 | Retraso en entrega AliExpress (batería, celdas, PIC) | Alta | Alto | Hacer pedido en S3–S4; tener proveedor local alternativo | Samuel |
| R2 | Solagro no tiene stock de rodillos Ø80mm | Media | Muy alto | Contactar en S3; buscar alternativas (importar, otro proveedor) | Samuel + Nicolás |
| R3 | Taller externo no puede mecanizar ejes a tiempo | Media | Alto | Reservar cita en S5; tener alternativa de taller privado | Samuel + Nicolás |
| R4 | Firmware más complejo de lo estimado (HX711 + LCD I2C) | Media | Medio | Iniciar en S5; usar librerías probadas; pruebas paralelas | Samuel |
| R5 | PCB con errores (requiere nueva fabricación) | Media | Alto | Revisión doble del esquemático antes de fabricar; prototipar en protoboard primero | Gabriel + Samuel |
| R6 | Presupuesto insuficiente para rodillos + pulidora | Media | Alto | Renegociar con solicitante; buscar alternativa técnica | Samuel + Todos |
| R7 | Embrague DLD6-05 no disponible en Colombia | Baja | Muy alto | Cotizar en S3; importar si es necesario desde China (3–4 sem) | Samuel |
| R8 | Motor de gasolina incompatible con alternador seleccionado | Baja | Alto | Verificar medidas de eje antes de comprar alternador | Santiago |
| R9 | Batería LiFePO4 de AliExpress no cumple especificaciones | Media | Medio | Comprar a proveedor con reseñas verificadas; tener plan B con batería de AGM | Samuel + Santiago |
| R10 | Retraso en impresión 3D (falla de impresora, material) | Media | Medio | Tener acceso a 2 impresoras; iniciar impresión desde S9 | Andrés |

---

## 5. PRESUPUESTO DETALLADO POR CATEGORÍA

### 5.1 Resumen por Categoría

| Categoría | Presupuesto Estimado COP | % del Total |
|---|---|---|
| Sistema mecánico (chasis, ejes, transmisión, taller) | $1.950.000 | 32.6% |
| Sistema de descascarillado (rodillos, pulidora, ventilador) | $1.200.000 | 20.1% |
| Sistema eléctrico de potencia (alternador, batería, boost, etc.) | $535.000 | 8.9% |
| Sistema electrónico de control (MCU, sensores, interfaz, PCB) | $419.040 | 7.0% |
| Manufactura aditiva FDM (material + impresión) | $200.000 | 3.3% |
| Cableado, conectores, herrería general | $150.000 | 2.5% |
| Documentación, herramientas, consumibles | $100.000 | 1.7% |
| Contingencia (10% sobre presupuesto estimado) | $420.000 | 7.0% |
| **TOTAL ESTIMADO** | **~$4.974.040** | **83.2%** |
| **MARGEN DISPONIBLE** | **~$1.025.960** | **17.1%** |
| **PRESUPUESTO TOTAL** | **$7.000.000** | **100%** |

> **Nota**: Los precios del BOM detallado en `04_BOM/BOM_Descascaradora_v1.xlsx` suman ~$5.980.000 COP incluyendo los ítems por confirmar. El margen de ~$1.020.000 COP cubre imprevistos y la posible diferencia entre cotizaciones y precios reales de compra.

### 5.2 Control de Gasto Semanal

Ver `10_Gestion/CONTROL_PRESUPUESTO.md` para el registro actualizado de:
- Gastos realizados con soporte (factura/recibo)
- Compromisos de pago (órdenes de compra)
- Proyección vs. presupuesto disponible
- Alertas si el gasto supera el 80% del presupuesto antes de la semana 10

---

## 6. INDICADORES DE SEGUIMIENTO (KPIs)

| KPI | Meta | Frecuencia | Responsable |
|-----|---|---|---|
| % tareas EDT completadas vs. plan | ≥ 90% por semana | Semanal | Samuel |
| % presupuesto comprometido vs. disponible | ≤ 85% hasta S10 | Semanal | Samuel |
| N° de pedidos con retraso > 1 semana | 0 | Semanal | Samuel |
| N° de actas semanales firmadas y archivadas | 100% | Semanal | Todos |
| N° de bitácoras actualizadas | 6/6 (todas) | Semanal | Todos |
| % del firmware completado (módulos) | Según EDT | Quincenal | Samuel |
| N° de planos CAD exportados a repositorio | Según EDT | Quincenal | Nicolás |
| Eficiencia descascarillado medida | ≥ 85% | S13 (prueba) | Nicolás |
| Capacidad medida | ≥ 150 kg/h | S13 (prueba) | Todos |

---

*Gestión del Proyecto DAMSPI-150 v2.0 | Abril 2026 | PAI 2017275 — Grupo B*
*Responsable de gestión: Samuel D. Sánchez C.*

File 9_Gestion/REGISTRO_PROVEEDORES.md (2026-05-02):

# REGISTRO DE PROVEEDORES Y COMPRAS — DAMSPI-150
## Responsable: Samuel D. Sánchez C. | Actualización: Semanal (cada lunes)

> **Este documento es el registro oficial de toda actividad de compras del proyecto.**
> Toda cotización, pedido, recepción o pago debe registrarse aquí el mismo día que ocurre.
> Samuel envía resumen al grupo cada semana por WhatsApp/Discord.

---

## 1. DIRECTORIO DE PROVEEDORES

### 1.1 Proveedores Confirmados / En Gestión

| ID | Proveedor | Tipo | Contacto | Teléfono / Email | Productos | Estado |
|----|---|---|---|---|---|---|
| P01 | **Solagro Colombia** | Nacional especializado | Área comercial | solagro.co / (ventas) | Rodillos PU Ø80mm, pulidora horizontal, repuestos descascaradora | 🔄 En contacto |
| P02 | **AliExpress** | Internacional | Plataforma online | aliexpress.com | Batería LiFePO4, celdas de carga, PIC18F4550, LCD 20×4 I2C | 🔄 Cotizando |
| P03 | **MercadoLibre Colombia** | Nacional online | mercadolibre.com.co | Embrague DLD6-05, SSR, electrónica general | 🔄 Cotizando |
| P04 | **Naylampmechatronics** | Nacional online | naylampmechatronics.com | HX711, módulos electrónicos, teclado 4×4 | ⏳ Por contactar |
| P05 | **Homecenter Bogotá** | Nacional retail | homecenter.com.co | Motor gasolina 6.5HP (ya adquirido) | ✅ Usado |
| P06 | **Ferretería Industrial** (TBD) | Nacional local | Por definir (Bogotá) | Perfiles acero 40×40, rodamientos, poleas, pernos | ⏳ Por contactar |
| P07 | **Siesa Industrial** | Nacional local | Local Bogotá | E-Stop industrial, pilotos LED Ø22mm, botones industriales | ⏳ Por contactar |
| P08 | **Taller externo UNAL** | Taller campus | Coordinar a través de Nicolás | Mecanizado ejes, soldadura chasis | ⏳ Por coordinar |
| P09 | **JLCPCB** | Internacional online | jlcpcb.com | Fabricación PCB (5 uds. mínimo) | ⏳ Requiere esquemático S7 |
| P10 | **Repuestos de moto Bogotá** | Nacional local | Zona automotriz Bogotá | Alternador de motocicleta 100–200W | ⏳ Por contactar |

---

## 2. REGISTRO DE COTIZACIONES
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

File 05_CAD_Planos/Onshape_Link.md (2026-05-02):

# CAD ONSHAPE — DAMSPI-150
## Modelos 3D y Planos de Fabricación

## Enlace al Modelo Compartido

> **⚠️ Actualizar este archivo con el enlace real de Onshape una vez creado el documento.**

```
URL Onshape: [PENDIENTE — Nicolás crea el documento en S3 y comparte aquí]

Permisos: Ver + Copiar (para todos los miembros del equipo)
Edición: Solo Nicolás, Andrés y Sebastián tienen permiso de edición.
```

## Estructura del Documento Onshape

```
DAMSPI-150 (documento principal)
├── Part Studios
│   ├── PS_Modulo1_Potencia
│   │   ├── Soporte_Alternador_v1
│   │   ├── Polea_Conducida_80mm
│   │   └── Carcasa_Modulo1
│   ├── PS_Modulo2_Descascarillado
│   │   ├── Bastidor_Rodillos
│   │   ├── Ajustador_Separacion
│   │   ├── Soporte_Ventilador
│   │   └── Tolva_Entrada
│   ├── PS_Modulo3_Control
│   │   ├── Carcasa_Panel_Control
│   │   ├── Soporte_Celdas_Carga
│   │   └── Plataforma_Pesaje
│   └── PS_Modulo4_Chasis
│       ├── Chasis_Principal
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

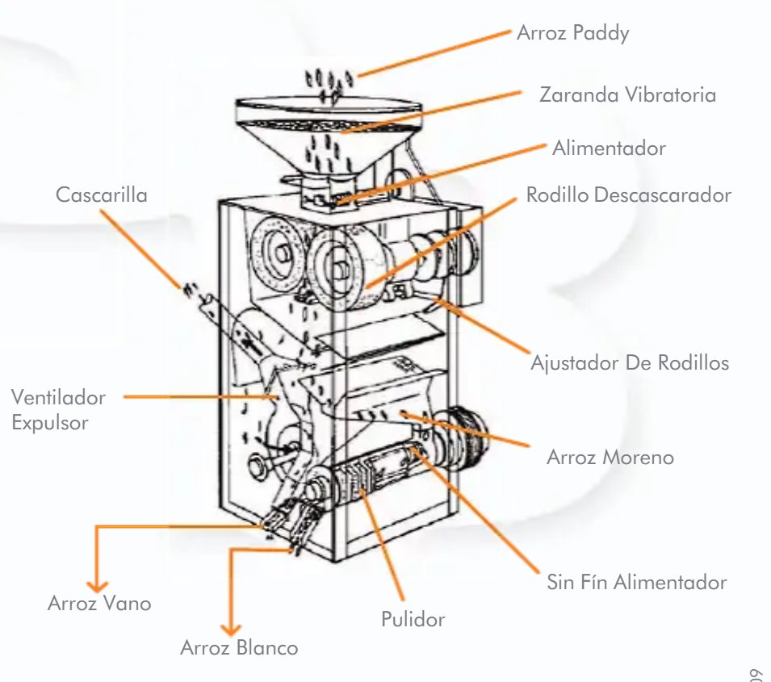
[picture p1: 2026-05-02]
01_Informe/boceto_arquitectura_modular.png

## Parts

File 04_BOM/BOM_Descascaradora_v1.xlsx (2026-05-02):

LISTA DE MATERIALES (BOM) — Descascaradora de Arroz Modular Semiautomática
Proyecto Aplicado de Ingeniería 2017275 — Universidad Nacional de Colombia — 1er Semestre 2026 | Grupo B
# | Ítem / Componente | Módulo | Descripción Técnica | Cantidad | Und. | Precio Unit. (COP) | Precio Total (COP) | Estado | Proveedor / Link | Observaciones
1 | Motor gasolina 6.5HP, 196cc, 3600RPM | Mod.1 — Potencia | Motor 4T gasolina, torque 12Nm, arranque retráctil, eje 3/4" cuñero. Ref SKU 625279. | 1 | und | 750000 | 750000 | ADQUIRIDO | Homecenter (homecenter.com.co) | Ya adquirido por el equipo
2 | Embrague electromagnético DLD6-05 tipo A | Mod.1 — Potencia | DC24V, monodisco seco, par de acoplamiento 6Nm, resp. <0.3s. Montaje en eje 19mm. | 1 | und | 300000 | 300000 | COTIZADO | MercadoLibre Colombia (mercadolibre.com.co) | Par de 6Nm suficiente para transmisión a rodillos
3 | Celda de carga tipo S — 10 kg | Mod.3 — Control | Aleación de aluminio, IP67, salida 2mV/V, conector 4 hilos. Para sistema de pesaje. | 4 | und | 57045 | 228180 | COTIZADO | AliExpress (item 1005008612967612) | 4 celdas en puente Wheatstone — carga máx. 40kg
4 | Módulo HX711 (ADC 24 bits) | Mod.3 — Control | Conversor A/D de 24 bits para celdas de carga. Ganancia 128/64/32x. Interfaz SPI/I2C. | 1 | und | 15000 | 15000 | Por adquirir | MercadoLibre Colombia / Naylampmechatronics | Compatible con PIC18F4550 por SPI
5 | PIC18F4550 (Microchip) | Mod.3 — Control | Microcontrolador 8 bits, 32KB Flash, USB nativo, 10-bit ADC, 48MHz. DIP-40. | 1 | und | 31018 | 31018 | COTIZADO | AliExpress (item 1005008943635084) | Justificado por USB, disponibilidad y documentación
6 | Pantalla Nokia 5110 LCD (PCD8544) | Mod.3 — Control | LCD 84×48 píxeles, SPI, retroiluminación, 3.3V. Legible en exterior. | 1 | und | 15000 | 15000 | Por adquirir | MercadoLibre Colombia / AliExpress | Interfaz de usuario del sistema de control
7 | Batería litio 24V / 5Ah (con BMS) | Mod.1 — Potencia | LiFePO4 o Li-Ion. BMS integrado. Corriente máx. descarga 10A. Autonomía ≥4h sistema electrónico. | 1 | und | 250000 | 250000 | COTIZADO | AliExpress (item 1005009963240184) | Carga por alternador de moto vía boost converter
8 | Alternador de motocicleta 100-200W | Mod.1 — Potencia | Generador AC trifásico o bifásico. Rectificador integrado o externo. Salida 13.8–14.5V DC. | 1 | und | 180000 | 180000 | Por adquirir | Mercado de repuestos motos Bogotá / MercadoLibre | Se adapta al eje secundario mediante brida
9 | Módulo rectificador + regulador 14V | Mod.1 — Potencia | Puente de diodos 15A + regulador de voltaje de moto. Para salida del alternador. | 1 | und | 35000 | 35000 | Por adquirir | MercadoLibre Colombia | Protección contra sobretensión por alternador
10 | Convertidor DC-DC Boost 14V→24V, 5A | Mod.1 — Potencia | Step-up converter para carga de batería 24V desde alternador de 14V. Eficiencia ≥85%. | 1 | und | 45000 | 45000 | Por adquirir | AliExpress / MercadoLibre | Necesario para cargar batería de 24V desde alternador de 14V
11 | Convertidor DC-DC Buck 24V→5V, 3A | Mod.3 — Control | LM2596 o MP1584. Alimenta PIC, pantalla, sensores. Estabilizado. | 2 | und | 12000 | 24000 | Por adquirir | MercadoLibre Colombia | Uno para MCU y sensores, otro de repuesto
12 | Relé de estado sólido 24VDC/10A | Mod.3 — Control | SSR DC-DC para control del embrague electromagnético. Aislamiento óptico. Sin rebote. | 1 | und | 25000 | 25000 | Por adquirir | MercadoLibre Colombia | Diodo flyback integrado para protección del embrague
13 | Acople flexible (jaw coupling) Ø19mm | Mod.1 — Potencia | Tipo araña, acero + elemento PU. Une eje motor al eje secundario. Absorbe desalineación. | 1 | und | 40000 | 40000 | Por adquirir | MercadoLibre Colombia / ferreterías industriales | Reduce vibración transmitida al alternador
14 | Par de rodillos de goma/PU | Mod.2 — Descascarillado | Ø80mm externo, núcleo acero, recubrimiento PU 20mm, dureza 40–60 Shore A, L=200mm activa. | 1 | par | 400000 | 400000 | Por adquirir (Solagro) | Solagro Colombia (solagro.co) | Principal elemento de trabajo. Cotizar directamente.
15 | Pulidora horizontal (Horizontal Abrasive Whitener) | Mod.2 — Descascarillado | Cilindro abrasivo horizontal, malla perforada, contrapeso ajustable. L aprox. 300mm. | 1 | und | 600000 | 600000 | Por adquirir (Solagro) | Solagro Colombia (solagro.co) | Módulo opcional de pulido. Solagro provee repuestos.
16 | Ventilador centrífugo | Mod.2 — Descascarillado | Caudal ≥0.15 m³/s, baja presión. Accionado por eje de transmisión. Separación cascarilla. | 1 | und | 200000 | 200000 | Por adquirir | Talleres locales / importación | Caudal de aire: 2.5–4.5 m/s en zona de separación
17 | Poleas en V (juego) | Mod.1/2 — Potencia/Descasc. | Poleas para correas tipo A y B. Diferentes diámetros para relaciones de transmisión requeridas. Fundición o aluminio. | 2 | juego | 180000 | 360000 | Por adquirir | Ferreterías industriales Bogotá / importación | Diámetros según cálculo final de transmisiones
18 | Correas en V (tipo A y B, juego) | Mod.1/2 — Potencia/Descasc. | Correas tipo A y B para transmisión de potencia. Gates o equivalente. | 1 | juego | 80000 | 80000 | Por adquirir | Ferreterías industriales Bogotá | Verificar tensión con regla de deflexión
19 | Rodamientos (juego) | Mod.2 — Descascarillado | SKF o FAG. Para ejes de rodillos, ventilador y Sin Fín. Sellados 2RS. | 1 | juego | 120000 | 120000 | Por adquirir | Distribuidores SKF Bogotá / MercadoLibre | Rodamientos 6004-2RS o equivalente para Ø20mm de eje
20 | Ejes de acero (material) | Mod.2 — Descascarillado | Acero de transmisión 1020 o 1045. Ø20–25mm, L=300–500mm c/u. Mecanizado en taller. | 1 | juego | 80000 | 80000 | Por adquirir | Acerías Bogotá / Ferrasa | 2 ejes para rodillos + 1 para Sin Fín + 1 eje secundario
21 | Perfiles acero cuadrado 40×40×3mm | Mod.4 — Chasis | ASTM A36. Para estructura portante y base motor. Total aprox. 10 ml. | 10 | ml | 18000 | 180000 | Por adquirir | Ferreterías industriales Bogotá | Corte y soldadura en taller. Pintura anticorrosión.
22 | Ángulos acero 50×50×5mm | Mod.4 — Chasis | ASTM A36. Para refuerzos y soportes. Total aprox. 4 ml. | 4 | ml | 15000 | 60000 | Por adquirir | Ferreterías industriales Bogotá | Complemento para estructura chasis
23 | Lámina acero inox AISI 304 (1.5mm) | Mod.2 — Descascarillado | Para canales, tolva interior y zonas de contacto con arroz. 1 lámina 1m×2m. | 1 | lam | 250000 | 250000 | Por adquirir | Aceros inoxidables Bogotá | Cumplimiento inocuidad alimentaria (Dec.1500/2007)
24 | Lámina galvanizada 1mm (guardas) | Mod.4 — Chasis | Para guardas de seguridad sobre correas y poleas. 1 lámina 1m×2m. | 1 | lam | 80000 | 80000 | Por adquirir | Ferreterías industriales Bogotá | Cumplimiento ISO 4254-1 guardas de seguridad
25 | Servomotor MG996R (válvula tolva) | Mod.3 — Control | Par 9.4–11 kg·cm, control PWM, 5V. Para actuación de compuerta de tolva. | 1 | und | 35000 | 35000 | Por adquirir | MercadoLibre Colombia / AliExpress | Alternativa: solenoide lineal 24V
26 | Ruedas (2 fijas + 1 giratoria c/freno) | Mod.4 — Chasis | Ø200mm, neumático baja presión para terreno irregular. Rodamiento sellado. | 3 | und | 35000 | 105000 | Por adquirir | Ferreterías / casas rodachinas Bogotá | Sistema de movilidad del equipo en campo
27 | Botón E-Stop hongo Ø40mm (NC) | Mod.3 — Control | Paro de emergencia normalmente cerrado. Cuerpo plástico, contacto 10A. | 1 | und | 25000 | 25000 | Por adquirir | MercadoLibre Colombia / Siesa Industrial | Cumplimiento seguridad ISO 11684
28 | Botones START / STOP industriales | Mod.3 — Control | Verde (START) y rojo (STOP). Ø22mm, 5A. Panel de control. | 2 | und | 15000 | 30000 | Por adquirir | MercadoLibre Colombia | Botones de inicio y paro del ciclo de descascarillado
29 | Pilotos LED 24V (verde, amarillo, rojo) | Mod.3 — Control | Indicadores de estado. Cuerpo metálico Ø22mm, 24VDC. | 3 | und | 12000 | 36000 | Por adquirir | MercadoLibre Colombia / Siesa Industrial | Estado del sistema visible para el operario
30 | Buzzer 5V | Mod.3 — Control | Alerta sonora 80dB. Para señal de peso alcanzado y errores. | 1 | und | 5000 | 5000 | Por adquirir | MercadoLibre Colombia / AliExpress | Integrado en panel de control
31 | Tornillería y elementos de fijación | General | Pernos M8, M10, M6, tuercas, arandelas, seguros de eje, cuñas. Acero inoxidable. | 1 | lote | 80000 | 80000 | Por adquirir | Ferreterías industriales Bogotá | Incluye hardware de ensamble rápido entre módulos
32 | Cable eléctrico (varios calibres) | Mod.1/3 — Potencia/Control | AWG 14 (potencia), AWG 22 (señales). Varios colores, 10m c/u. | 1 | lote | 40000 | 40000 | Por adquirir | Ferreterías eléctricas Bogotá | Cableado interno y entre módulos
33 | Manufactura externa (taller) | General | Mecanizado de ejes, corte de perfiles, soldadura de estructura. Estimado. | 1 | serv | 700000 | 700000 | Estimado | Taller externo Bogotá / Instalaciones UNAL | Incluye mecanizado de ejes y soldadura de chasis
34 | Contingencia (10%) | General | Reserva para imprevistos, envíos, ajustes de diseño. | 1 | glob | 618000 | 618000 | Reserva | N/A | 10% sobre subtotal de ítems directos
TOTAL ESTIMADO (COP) |  |  |  |  |  |  | 6022198 | Presupuesto disponible: $7.000.000 COP | Motor ya adquirido

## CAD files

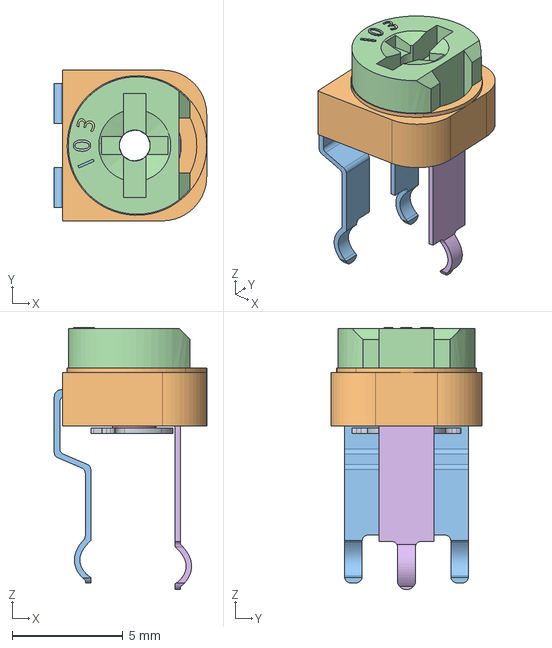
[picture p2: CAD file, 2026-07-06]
08_Electrica/kicad/Placa__principal/3dmodels/Poti_10kohm.stp
6.88 x 6.80 x 11.8 mm

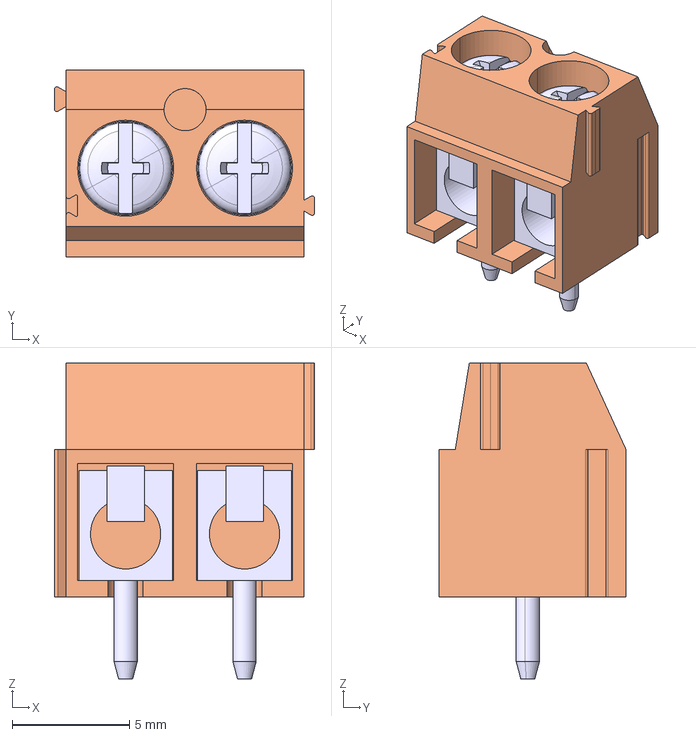
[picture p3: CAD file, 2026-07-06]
08_Electrica/kicad/Placa__principal/3dmodels/BORNERA2.stp
11.1 x 8.00 x 13.5 mm

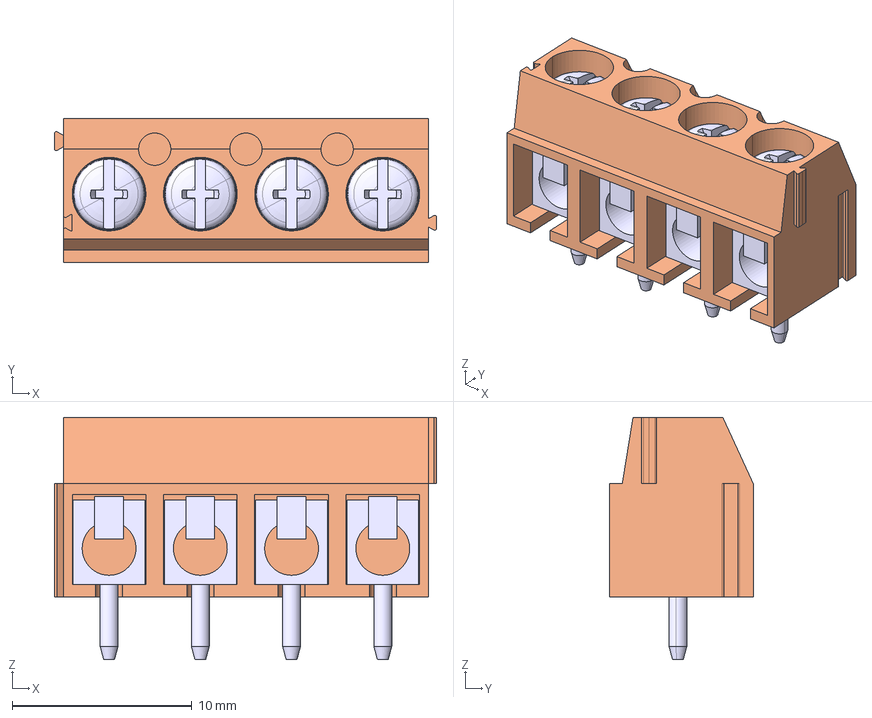
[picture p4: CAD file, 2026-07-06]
08_Electrica/kicad/Placa__principal/3dmodels/BORNERA4.stp
21.3 x 8.00 x 13.5 mm

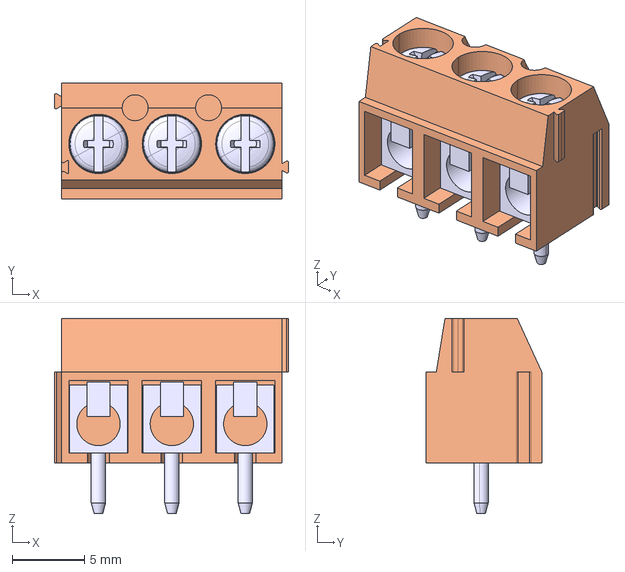
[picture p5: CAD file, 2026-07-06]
08_Electrica/kicad/Placa__principal/3dmodels/BORNERA3.stp
16.2 x 8.00 x 13.5 mm

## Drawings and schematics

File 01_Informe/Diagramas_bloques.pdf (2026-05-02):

# Esquema Proceso

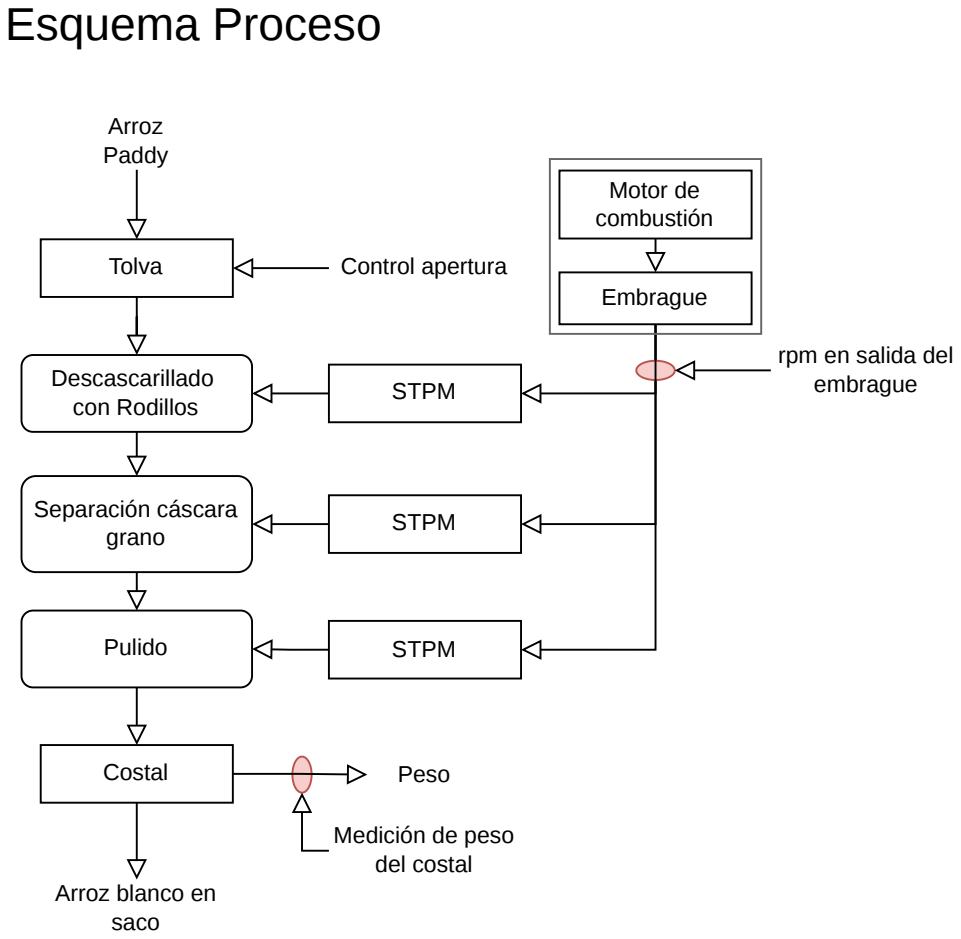
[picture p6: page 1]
Descascarillado con Rodillos; Control apertura; STPM; Tolva; Separación cáscara grano; Pulido; Costal; Peso; Motor de combustión; Embrague; Arroz Paddy

rpm en salida del
embrague

Medición de peso
del costal

Arroz blanco en
saco

# Rutina Trabajando

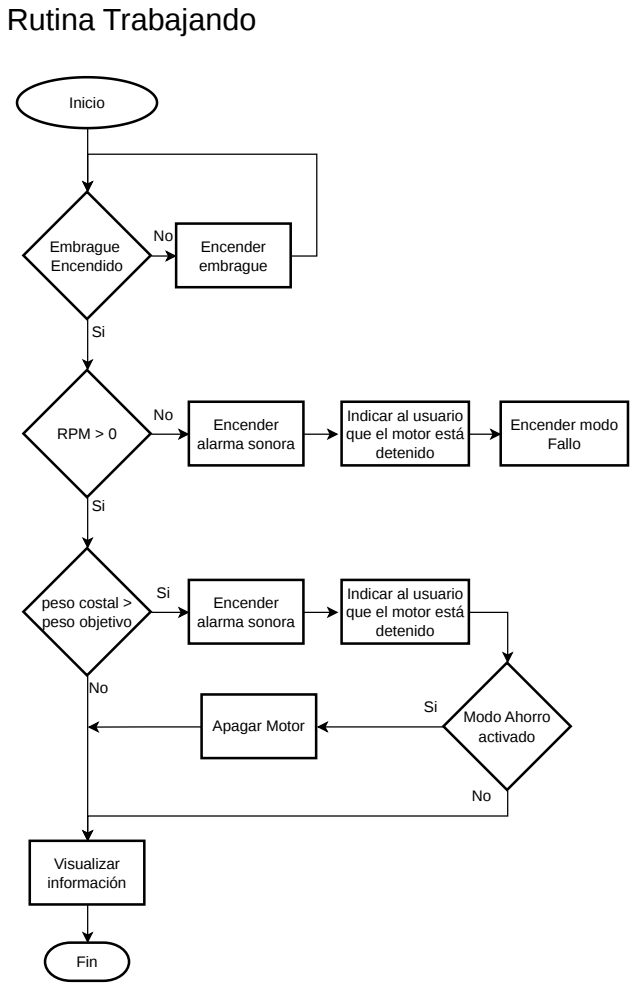
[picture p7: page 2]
Embrague Encendido; Inicio; Encender embrague; RPM > 0; Encender; alarma sonora; Indicar al usuario; peso costal > peso objetivo; Encender alarma sonora; Modo Ahorro; Fin; Encender modo Fallo; Visualizar información

que el motor está
detenido

activado Apagar Motor

# Rutina Fallo

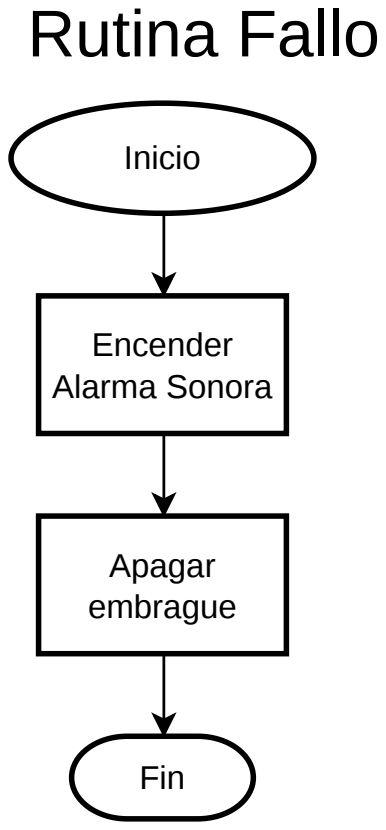
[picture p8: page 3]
Inicio; Fin; Encender Alarma Sonora; Apagar embrague

# Rutina Esperar

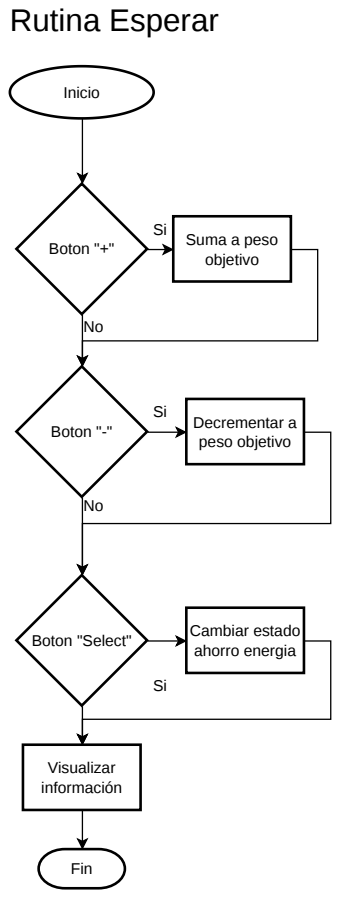
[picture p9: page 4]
Boton "+"; Inicio; Suma a peso objetivo; Boton "-"; Decrementar a; peso objetivo; Boton "Select"; Cambiar estado; ahorro energia; Fin; Visualizar información

# Rutina Mantenimiento

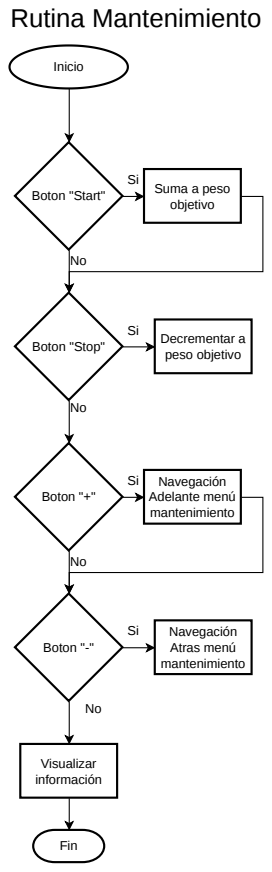
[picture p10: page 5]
Boton "Start"; Inicio; Suma a peso objetivo; Boton "Stop"; Decrementar a; peso objetivo; Fin; Visualizar información; Boton "+"; Navegación Adelante menú mantenimiento; Boton "-"; Navegación Atras menú mantenimiento

# Rutina Main

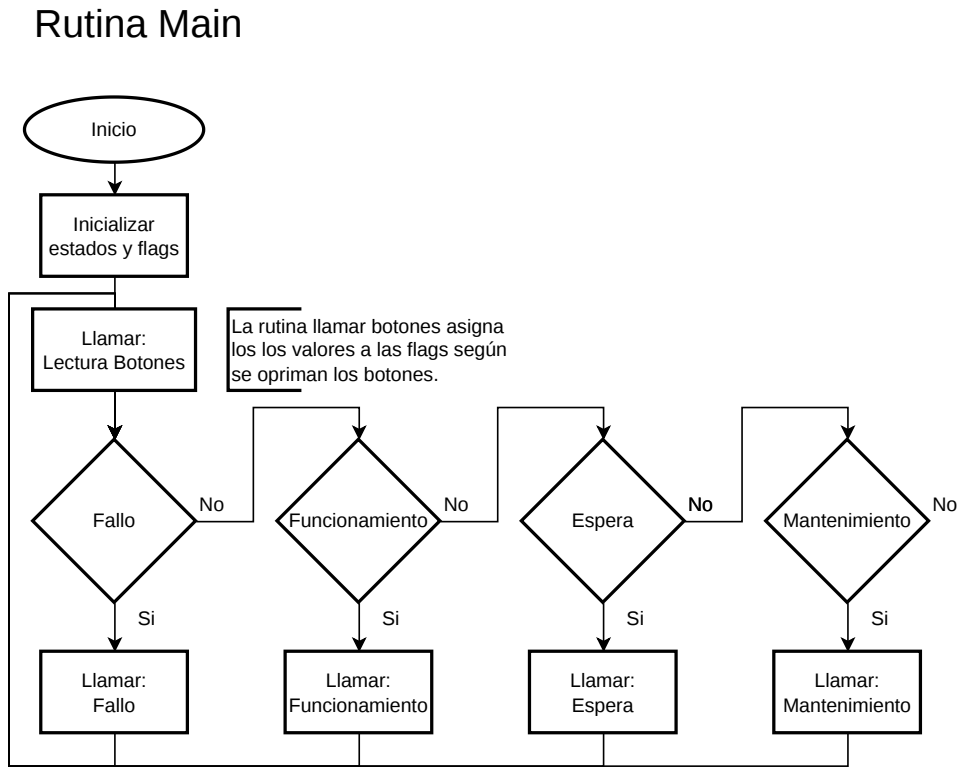
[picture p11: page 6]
Fallo; Inicio; Llamar: Fallo; Inicializar estados y flags; Funcionamiento; Llamar: Funcionamiento; Espera; Llamar: Espera; Mantenimiento; Llamar: Mantenimiento; Llamar: Lectura Botones

La rutina llamar botones asigna
los los valores a las flags según
se opriman los botones.

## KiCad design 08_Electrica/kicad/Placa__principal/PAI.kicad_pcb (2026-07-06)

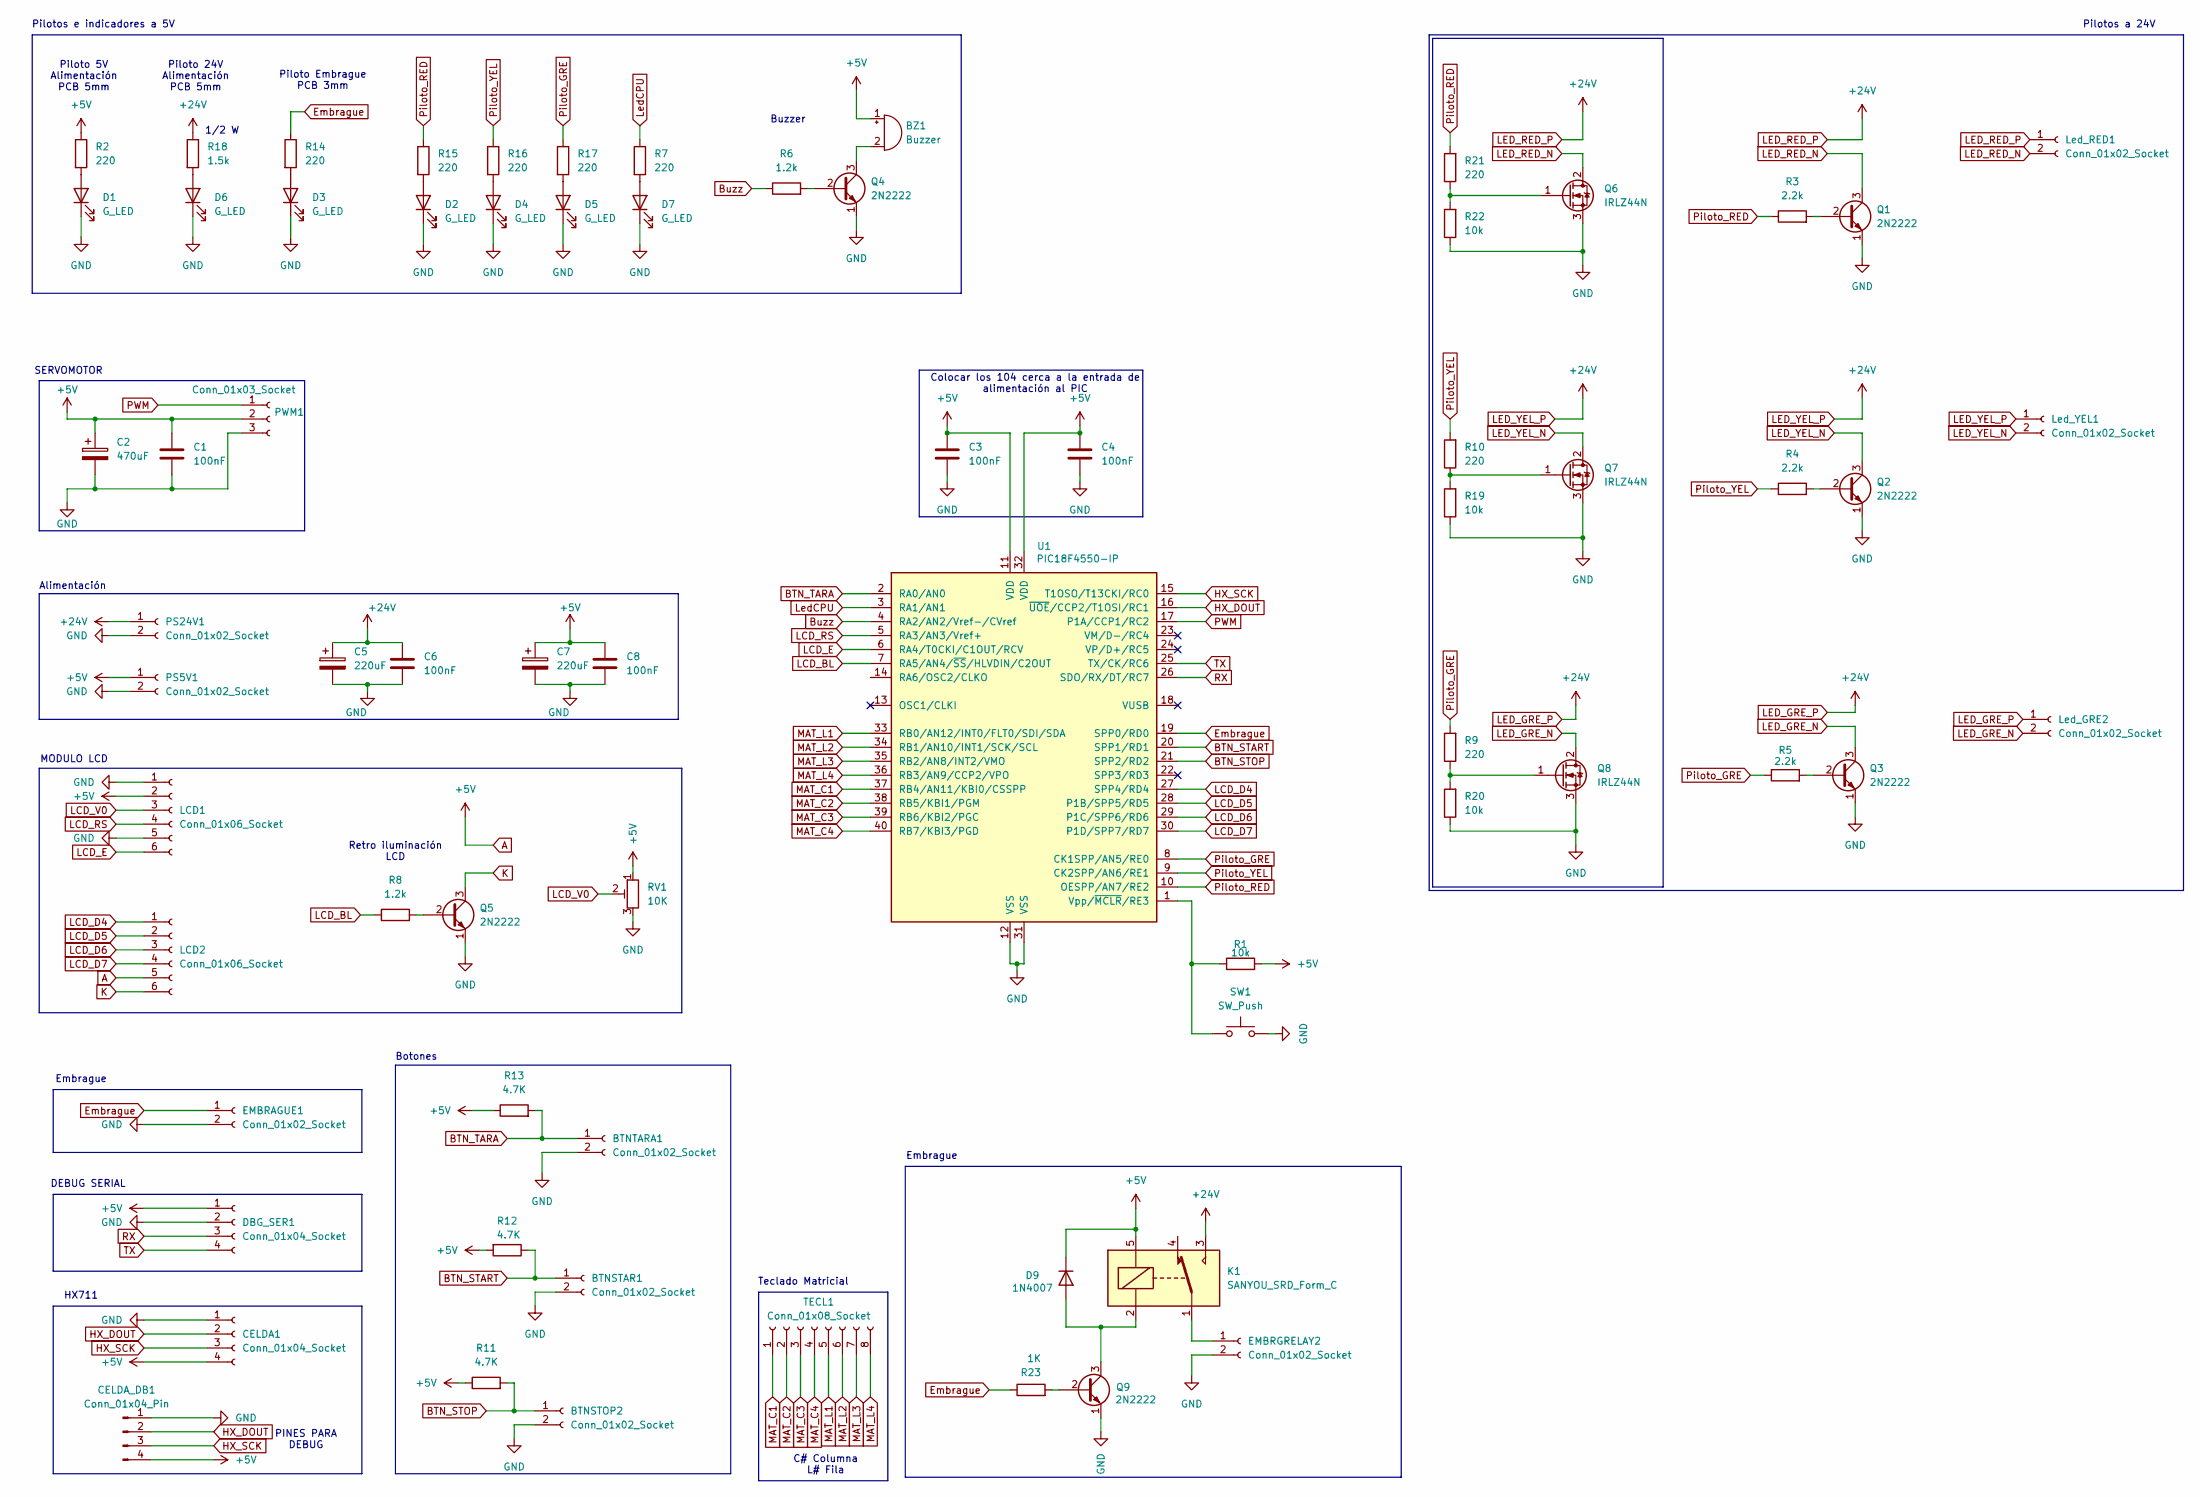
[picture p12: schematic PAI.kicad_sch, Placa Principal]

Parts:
BTNSTAR1: Conn_01x02_Socket; TerminalBlock_bornier-2_P5.08mm
BTNSTOP2: Conn_01x02_Socket; TerminalBlock_bornier-2_P5.08mm
BTNTARA1: Conn_01x02_Socket; TerminalBlock_bornier-2_P5.08mm
BZ1: Buzzer; Buzzer_12x9.5RM7.6
C1, C3, C4, C6, C8: 100nF; C_Disc_D6.0mm_W2.5mm_P5.00mm
C2: 470uF; CP_Radial_D10.0mm_P5.00mm
C5, C7: 220uF; CP_Radial_D10.0mm_P5.00mm
CELDA1: Conn_01x04_Socket; TerminalBlock_bornier-4_P5.08mm
CELDA_DB1: Conn_01x04_Pin; PinSocket_1x04_P2.54mm_Vertical
D1, D2, D3, D4, D5, D6, D7: G_LED; LED_D5.0mm
D9: 1N4007; D_DO-41_SOD81_P10.16mm_Horizontal
DBG_SER1: Conn_01x04_Socket; PinHeader_1x04_P2.54mm_Vertical
EMBRAGUE1: Conn_01x02_Socket; PinHeader_1x02_P2.54mm_Vertical
EMBRGRELAY2: Conn_01x02_Socket; TerminalBlock_bornier-2_P5.08mm
K1: SANYOU_SRD_Form_C; Relay_SPDT_SANYOU_SRD_Series_Form_C
LCD1, LCD2: Conn_01x06_Socket; PinHeader_1x06_P2.54mm_Vertical
Led_GRE2: Conn_01x02_Socket; TerminalBlock_bornier-2_P5.08mm
Led_RED1: Conn_01x02_Socket; TerminalBlock_bornier-2_P5.08mm
Led_YEL1: Conn_01x02_Socket; TerminalBlock_bornier-2_P5.08mm
PS5V1, PS24V1: Conn_01x02_Socket; TerminalBlock_bornier-2_P5.08mm
PWM1: Conn_01x03_Socket; TerminalBlock_bornier-3_P5.08mm
Q1, Q2, Q3, Q4, Q5, Q9: 2N2222; TO-92L_Wide
Q6, Q7, Q8: IRLZ44N; TO-220-3_Vertical
R1, R19, R20, R22: 10k; R_Axial_DIN0207_L6.3mm_D2.5mm_P10.16mm_Horizontal
R2, R7, R9, R10, R14, R15, R16, R17, R21: 220; R_Axial_DIN0207_L6.3mm_D2.5mm_P10.16mm_Horizontal
R3, R4, R5: 2.2k; R_Axial_DIN0207_L6.3mm_D2.5mm_P10.16mm_Horizontal
R6: 1.2k; R_Axial_DIN0207_L6.3mm_D2.5mm_P10.16mm_Horizontal
R8: 1.2k; R_Axial_DIN0207_L6.3mm_D2.5mm_P15.24mm_Horizontal
R11, R12: 4.7K; R_Axial_DIN0207_L6.3mm_D2.5mm_P10.16mm_Horizontal
R13: 4.7K; R_Axial_DIN0207_L6.3mm_D2.5mm_P15.24mm_Horizontal
R18: 1.5k; R_Axial_DIN0411_L9.9mm_D3.6mm_P15.24mm_Horizontal
R23: 1K; R_Axial_DIN0207_L6.3mm_D2.5mm_P10.16mm_Horizontal
RV1: 10K; Potentiometer_Runtron_RM-065_Vertical
SW1: SW_Push; SW_PUSH_6mm
TECL1: Conn_01x08_Socket; PinHeader_1x08_P2.54mm_Vertical
U1: PIC18F4550-IP; DIP-40_W15.24mm_Socket

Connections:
A: BZ1.1 (+), C1.1, C2.1, C3.1, C4.1, C7.1, C8.1, CELDA1.4, CELDA_DB1.4, D9.1 (K), DBG_SER1.1, K1.5, LCD1.2, LCD2.5, PS5V1.1, PWM1.2, R1.2, R2.1, R11.1, R12.2, R13.1, RV1.1, U1.11 (VDD), U1.32 (VDD)
BTN_START: BTNSTAR1.1, R12.1, U1.20 (SPP1/RD1)
BTN_STOP: BTNSTOP2.1, R11.2, U1.21 (SPP2/RD2)
BTN_TARA: BTNTARA1.1, R13.2, U1.2 (RA0/AN0)
Buzz: R6.1, U1.4 (RA2/AN2/Vref-/CVref)
Embrague: EMBRAGUE1.1, R14.1, R23.1, U1.19 (SPP0/RD0)
GND: BTNSTAR1.2, BTNSTOP2.2, BTNTARA1.2, C1.2, C2.2, C3.2, C4.2, C5.2, C6.2, C7.2, C8.2, CELDA1.1, CELDA_DB1.1, D1.1 (K), D2.1 (K), D3.1 (K), D4.1 (K), D5.1 (K), D6.1 (K), D7.1 (K), DBG_SER1.2, EMBRAGUE1.2, EMBRGRELAY2.2, LCD1.1, LCD1.5, PS5V1.2, PS24V1.2, PWM1.3, Q1.1 (E), Q2.1 (E), Q3.1 (E), Q4.1 (E), Q5.1 (E), Q6.3 (S), Q7.3 (S), Q8.3 (S), Q9.1 (E), R19.1, R20.1, R22.1, RV1.3, SW1.2, U1.12 (VSS), U1.31 (VSS)
HX_DOUT: CELDA1.2, CELDA_DB1.2, U1.16 (~UOE/CCP2/T1OSI/RC1)
HX_SCK: CELDA1.3, CELDA_DB1.3, U1.15 (T1OSO/T13CKI/RC0)
K: LCD2.6, Q5.3 (C)
LCD_BL: R8.1, U1.7 (RA5/AN4/~SS/HLVDIN/C2OUT)
LCD_D4: LCD2.1, U1.27 (SPP4/RD4)
LCD_D5: LCD2.2, U1.28 (P1B/SPP5/RD5)
LCD_D6: LCD2.3, U1.29 (P1C/SPP6/RD6)
LCD_D7: LCD2.4, U1.30 (P1D/SPP7/RD7)
LCD_E: LCD1.6, U1.6 (RA4/T0CKI/C1OUT/RCV)
LCD_RS: LCD1.4, U1.5 (RA3/AN3/Vref+)
LCD_V0: LCD1.3, RV1.2
LED_GRE_N: Led_GRE2.2, Q3.3 (C), Q8.2 (D)
LED_GRE_P: C5.1, C6.1, K1.3, Led_GRE2.1, Led_RED1.1, Led_YEL1.1, PS24V1.1, R18.1
LED_RED_N: Led_RED1.2, Q1.3 (C), Q6.2 (D)
LED_YEL_N: Led_YEL1.2, Q2.3 (C), Q7.2 (D)
LedCPU: R7.1, U1.3 (RA1/AN1)
MAT_C1: TECL1.1, U1.37 (RB4/AN11/KBI0/CSSPP)
MAT_C2: TECL1.2, U1.38 (RB5/KBI1/PGM)
MAT_C3: TECL1.3, U1.39 (RB6/KBI2/PGC)
MAT_C4: TECL1.4, U1.40 (RB7/KBI3/PGD)
MAT_L1: TECL1.5, U1.33 (RB0/AN12/INT0/FLT0/SDI/SDA)
MAT_L2: TECL1.6, U1.34 (RB1/AN10/INT1/SCK/SCL)
MAT_L3: TECL1.7, U1.35 (RB2/AN8/INT2/VMO)
MAT_L4: TECL1.8, U1.36 (RB3/AN9/CCP2/VPO)
unnamed: BZ1.2 (-), Q4.3 (C)
unnamed: D1.2 (A), R2.2
unnamed: D2.2 (A), R15.2
unnamed: D3.2 (A), R14.2
unnamed: D4.2 (A), R16.2
unnamed: D5.2 (A), R17.2
unnamed: D6.2 (A), R18.2
unnamed: D7.2 (A), R7.2
unnamed: D9.2 (A), K1.2, Q9.3 (C)
unnamed: EMBRGRELAY2.1, K1.1
unnamed: Q1.2 (B), R3.2
unnamed: Q2.2 (B), R4.2
unnamed: Q3.2 (B), R5.2
unnamed: Q4.2 (B), R6.2
unnamed: Q5.2 (B), R8.2
unnamed: Q6.1 (G), R21.1, R22.2
unnamed: Q7.1 (G), R10.1, R19.2
unnamed: Q8.1 (G), R9.1, R20.2
unnamed: Q9.2 (B), R23.2
unnamed: R1.1, SW1.1, U1.1 (Vpp/~MCLR/RE3)
PWM: PWM1.1, U1.17 (P1A/CCP1/RC2)
Piloto_GRE: R5.1, R9.2, R17.1, U1.8 (CK1SPP/AN5/RE0)
Piloto_RED: R3.1, R15.1, R21.2, U1.10 (OESPP/AN7/RE2)
Piloto_YEL: R4.1, R10.2, R16.1, U1.9 (CK2SPP/AN6/RE1)
RX: DBG_SER1.3, U1.26 (SDO/RX/DT/RC7)
TX: DBG_SER1.4, U1.25 (TX/CK/RC6)

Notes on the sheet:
Buzzer
Pilotos a 24V
HX711
Piloto 5V Alimentación PCB 5mm
Pilotos e indicadores a 5V
Embrague
Alimentación
PINES PARA DEBUG
C# Columna L# Fila
Retro iluminación LCD
Botones
Piloto Embrague PCB 3mm
MODULO LCD
DEBUG SERIAL
SERVOMOTOR
Piloto 24V Alimentación PCB 5mm
Teclado Matricial
Colocar los 104 cerca a la entrada de alimentación al PIC
1/2 W

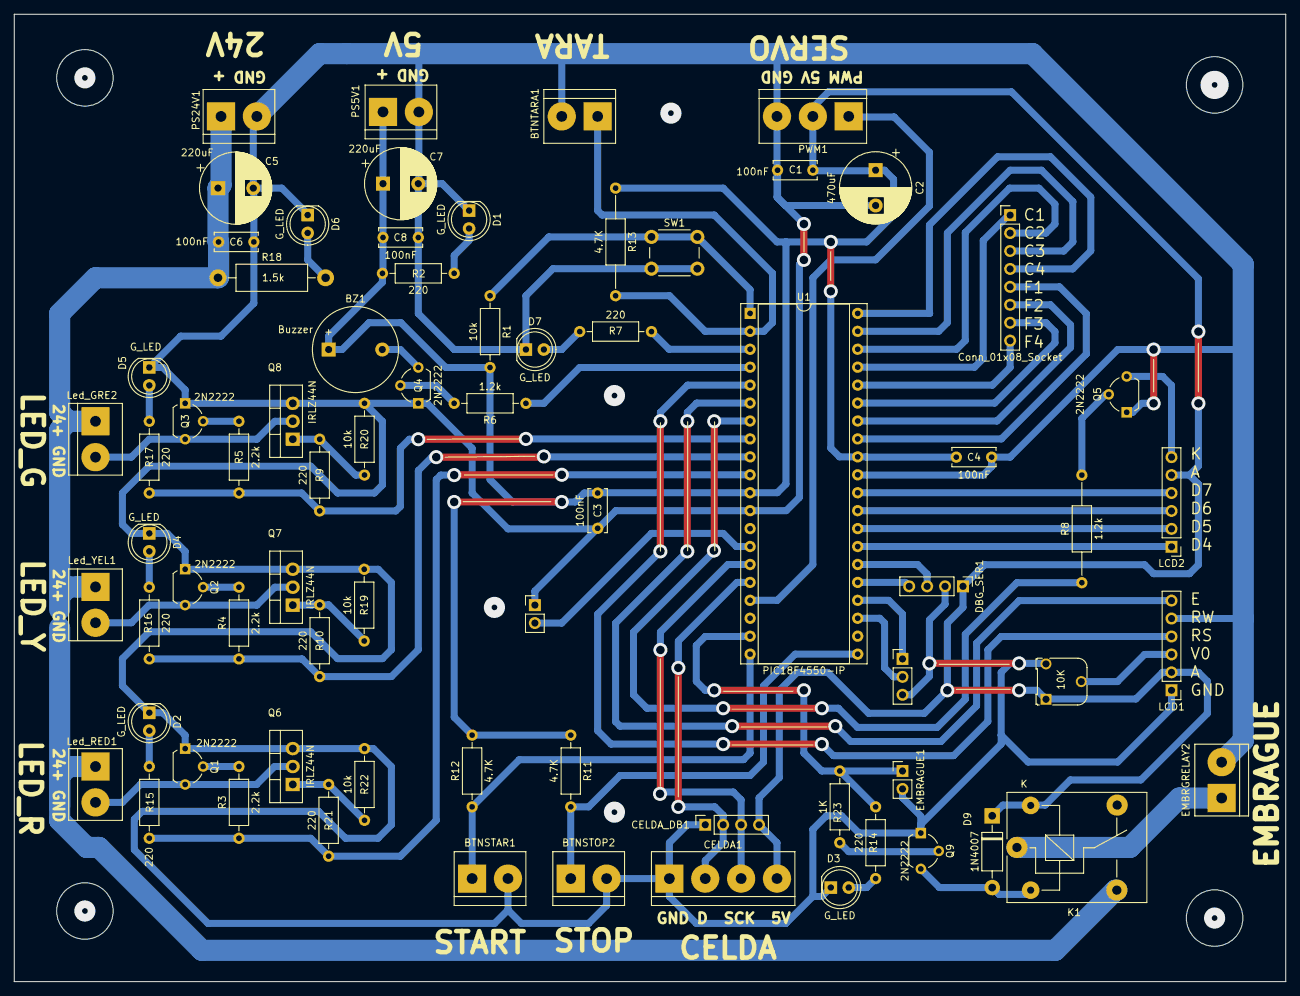
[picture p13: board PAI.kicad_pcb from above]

Board: 2 copper layers, 180.1 x 137.0 mm, 70 parts (0 on the bottom side), 57 nets.

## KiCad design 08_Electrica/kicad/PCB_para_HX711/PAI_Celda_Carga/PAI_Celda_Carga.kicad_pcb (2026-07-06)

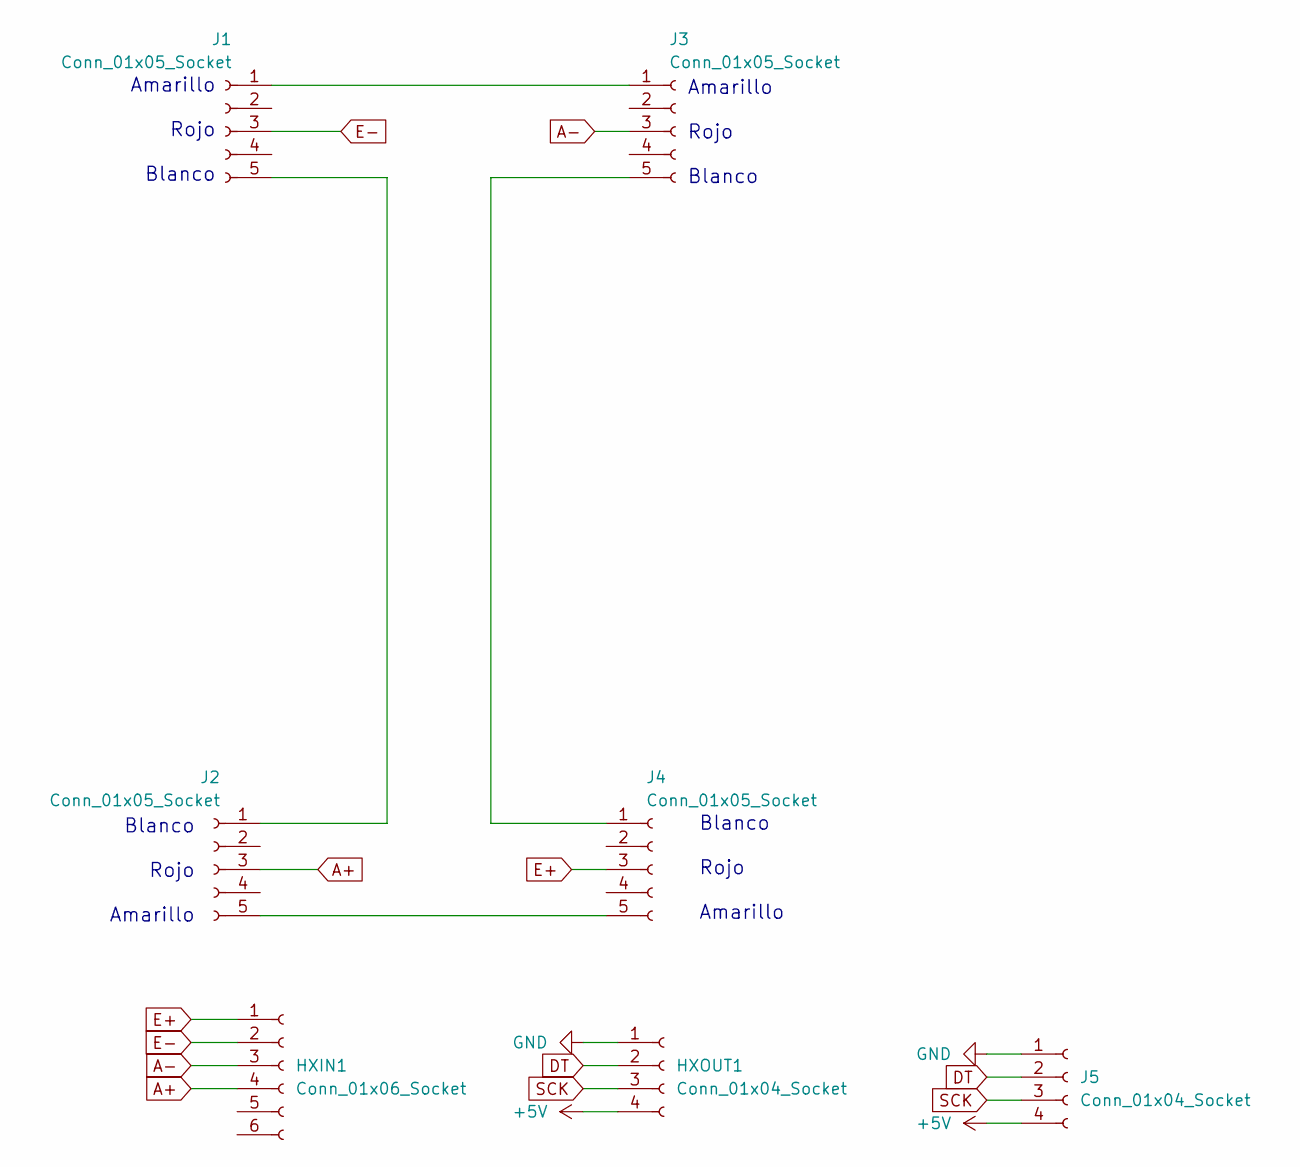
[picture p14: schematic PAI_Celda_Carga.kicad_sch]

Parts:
HXIN1: Conn_01x06_Socket; PinSocket_1x06_P2.54mm_Vertical
HXOUT1: Conn_01x04_Socket; PinSocket_1x04_P2.54mm_Vertical
J1, J2, J3, J4: Conn_01x05_Socket; PinSocket_1x05_P2.54mm_Vertical
J5: Conn_01x04_Socket; TerminalBlock_bornier-4_P5.08mm

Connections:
+5V: HXOUT1.4, J5.4
A+: HXIN1.4, J2.3
A-: HXIN1.3, J3.3
DT: HXOUT1.2, J5.2
E+: HXIN1.1, J4.3
E-: HXIN1.2, J1.3
GND: HXOUT1.1, J5.1
unnamed: J1.1, J3.1
unnamed: J1.5, J2.1
unnamed: J2.5, J4.5
unnamed: J3.5, J4.1
SCK: HXOUT1.3, J5.3

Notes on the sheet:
Amarillo Rojo Blanco
Blanco Rojo Amarillo
Blanco Rojo Amarillo

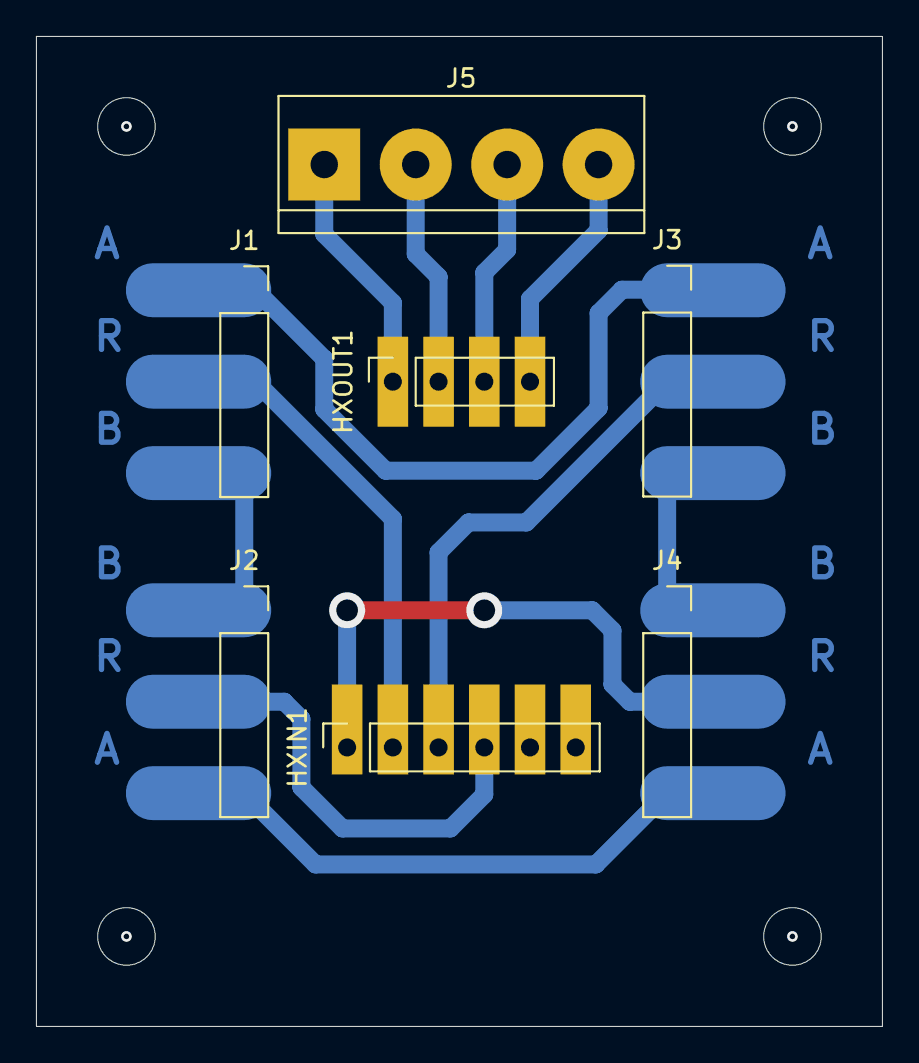
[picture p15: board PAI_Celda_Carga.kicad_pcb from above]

Board: 2 copper layers, 47.0 x 55.0 mm, 7 parts (0 on the bottom side), 12 nets.

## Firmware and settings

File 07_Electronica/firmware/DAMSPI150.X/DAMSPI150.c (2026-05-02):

/*
 * DAMSPI-150 — Descascaradora de Arroz Modular Semiautomática con Pesaje Integrado
 * Firmware PIC18F4550 — Módulo 3: Control, Pesaje e Interfaz
 *
 * Proyecto Aplicado de Ingeniería 2017275 | Grupo B | 1er Semestre 2026
 * Universidad Nacional de Colombia
 *
 * Autores:
 *   Samuel D. Sánchez C.  — Arquitectura, FSM, HX711, drivers
 *   Gabriel E. Bojacá M.  — Esquemático, LCD I2C, teclado, pilotos
 *
 * Hardware:
 *   MCU         : PIC18F4550 DIP-40 @ 8 MHz (oscilador interno)
 *   Pantalla    : LCD 20x4 HD44780 + PCF8574 I2C (0x27) — 5V nativo
 *   Teclado     : Matricial 4x4 membrana — PORTB completo (KBI)
 *   Pesaje      : 4x Celdas tipo S 10kg en puente Wheatstone + HX711 ADC 24 bits
 *   Embrague    : DLD6-05 24VDC via SSR 24VDC/10A (RD3)
 *   Servo tolva : MG996R via PWM CCP1 50Hz (RC2)
 *   E-Stop      : NC hardware en línea 24V + lectura estado en RA4
 *   Buzzer      : Activo 5V (RD4)
 *   LEDs        : Piloto Verde (RD5), Amarillo (RD6), Rojo (RD7) via 2N2222
 *
 * Compilador : XC8 >= 3.0
 * IDE        : MPLAB X >= 6.0
 * Programador: PICkit 3 o PICkit 4 (ICSP)
 *
 * Ver documentacion completa en: 08_Electronica/GUIA_ELECTRONICA.md
 */

// ============================================================
// INCLUDES Y CONFIGURACION
// ============================================================
#include <xc.h>
#include <stdint.h>
#include <stdbool.h>
#include <string.h>
#include "LibLCD_I2C_XC8.h"

// Configuracion del PIC18F4550
#pragma config FOSC   = INTOSCIO_EC  // Oscilador interno 8 MHz
#pragma config WDT    = OFF
#pragma config PWRT   = ON
#pragma config MCLRE  = ON
#pragma config LVP    = OFF
#pragma config PBADEN = OFF          // PORTB digital al reset
#pragma config BOR    = OFF
#pragma config STVREN = OFF

#define _XTAL_FREQ  8000000UL

// ============================================================
// PINES
// ============================================================
#define HX_SCK      RD0             // HX711 clock (salida)
#define HX_DOUT     RD1             // HX711 data  (entrada)
#define SSR_PIN     RD3             // SSR embrague (salida)
#define BUZZER_PIN  RD4             // Buzzer activo 5V
#define LED_VERDE   RD5             // Piloto LED verde (via 2N2222)
#define LED_AMARILLO RD6            // Piloto LED amarillo
#define LED_ROJO    RD7             // Piloto LED rojo
#define ESTOP_PIN   RA4             // E-Stop NC (LOW = presionado)
#define START_PIN   RA5             // Boton START (LOW = presionado)
#define STOP_PIN    RE0             // Boton STOP  (LOW = presionado)

// Configuracion servo CCP1 (RC2) — 50 Hz @ 8 MHz, prescaler 1:16, PR2=249
#define SERVO_CERRADO   25          // 1.0 ms → 0°
#define SERVO_ABIERTO   50          // 2.0 ms → 180°

// Configuracion LCD I2C
#define LCD_ADDR    0x27            // Direccion I2C modulo PCF8574

// ============================================================
// MAQUINA DE ESTADOS
// ============================================================
typedef enum {
    ST_INICIO,
    ST_ESPERA,
    ST_ASK,
    ST_COUNT,
    ST_COMPLETADO,
    ST_MENU,
    ST_EMERGENCIA
} EstadoSistema_t;

// ============================================================
// VARIABLES GLOBALES
// ============================================================
volatile EstadoSistema_t estado = ST_INICIO;

// Pesaje
volatile int32_t  offset_tara       = 0;
volatile float    factor_calibracion = 1.0f;  // raw/kg (calibrar con masa conocida)
volatile float    peso_kg           = 0.0f;
volatile float    peso_objetivo_kg  = 50.0f;
volatile uint8_t  bultos            = 0;

// Teclado
volatile uint8_t  tecla             = 0;
volatile bool     ok                = false;
volatile bool     ask               = false;
volatile uint8_t  input_count       = 0;
volatile uint16_t objetivo_temp     = 0;

// Control
volatile bool     emergency         = false;
volatile uint8_t  counter_inact     = 0;    // contador de inactividad (unidades: interrupciones Timer0)

// ============================================================
// PROTOTIPOS DE FUNCIONES
// ============================================================

// HX711
int32_t  hx711_leer_raw(void);
int32_t  hx711_leer_promedio(uint8_t n);
float    calcular_peso(int32_t raw);
void     realizar_tara(void);

// LCD I2C
void     lcd_mostrar_espera(void);
void     lcd_mostrar_peso(void);
void     lcd_mostrar_completado(void);
void     lcd_mostrar_emergencia(void);
void     lcd_mostrar_menu(void);
void     lcd_mostrar_ask(void);

// Teclado
uint8_t  escanear_teclado(void);
void     procesar_tecla(uint8_t t);

// Actuadores
void     servo_set(uint8_t pos);
void     embrague_on(void);
void     embrague_off(void);

// Alertas
void     beep(uint16_t ms);
void     beep_completado(void);
void     leds_set(bool verde, bool amarillo, bool rojo);

// EEPROM
void     EEPROM_Write(uint8_t addr, uint8_t data);
uint8_t  EEPROM_Read(uint8_t addr);
void     guardar_calibracion(void);
void     cargar_calibracion(void);

// Inicializacion
void     initPorts(void);
void     initInterrupts(void);
void     initPWM(void);

// ISR
void __interrupt() ISR(void);

// ============================================================
// MAIN
// ============================================================
void main(void) {
    initPorts();
    initInterrupts();
    initPWM();

    // Inicializar LCD I2C
    LCD_I2C_Init(LCD_ADDR);
    LCD_I2C_Clear();
    LCD_I2C_SetCursor(0, 0);
    LCD_I2C_Print("  DAMSPI-150    ");
    LCD_I2C_SetCursor(0, 1);
    LCD_I2C_Print("Iniciando...    ");
    __delay_ms(2000);

    // Cargar calibracion desde EEPROM
    cargar_calibracion();

    // Tara automatica al inicio
    realizar_tara();

    estado = ST_ESPERA;

    // ============================================================
    // LOOP PRINCIPAL
    // ============================================================
    while (1) {

        // Leer E-Stop en todo momento
        if (!ESTOP_PIN && !emergency) {
            emergency = true;
            estado = ST_EMERGENCIA;
        }

        switch (estado) {

            // ------------------------------------------------
            case ST_ESPERA:
                leds_set(0, 1, 0);          // LED amarillo
                embrague_off();
                servo_set(SERVO_CERRADO);
                lcd_mostrar_espera();
                lcd_mostrar_peso();

                if (!START_PIN || tecla == 'A') {
                    tecla = 0;
                    estado = ST_COUNT;
                    beep(100);
                    beep(100);
                }
                if (tecla == 'C') {
                    tecla = 0;
                    estado = ST_MENU;
                }
                if (tecla == '*') {
                    tecla = 0;
                    realizar_tara();
                }
                break;

            // ------------------------------------------------
            case ST_ASK:
                lcd_mostrar_ask();
                ask = true;
                ok  = false;
                input_count  = 0;
                objetivo_temp = 0;

                while (!ok) {
                    if (emergency) { estado = ST_EMERGENCIA; break; }
                    __delay_ms(50);
                }
                ask = false;

                // Validar objetivo
                if (objetivo_temp == 0 || objetivo_temp > 60) {
                    LCD_I2C_Clear();
                    LCD_I2C_SetCursor(0, 0);
                    LCD_I2C_Print("  Valor errado! ");
                    LCD_I2C_SetCursor(0, 1);
                    LCD_I2C_Print("  Rango: 1-60kg ");
                    __delay_ms(2000);
                    estado = ST_ESPERA;
                } else {
                    peso_objetivo_kg = (float)objetivo_temp;
                    EEPROM_Write(0x02, (uint8_t)objetivo_temp);
                    estado = ST_COUNT;
                }
                break;

            // ------------------------------------------------
            case ST_COUNT:
                leds_set(1, 0, 0);          // LED verde
                embrague_on();
                servo_set(SERVO_ABIERTO);

                // Leer peso (5 Hz)
                {
                    int32_t raw = hx711_leer_promedio(16);
                    peso_kg = calcular_peso(raw);
                    lcd_mostrar_peso();
                }

                // Verificar objetivo
                if (peso_kg >= peso_objetivo_kg) {
                    embrague_off();
                    servo_set(SERVO_CERRADO);
                    bultos++;
                    EEPROM_Write(0x00, bultos);
                    beep_completado();
                    estado = ST_COMPLETADO;
                    break;
                }

                // STOP manual
                if (!STOP_PIN || tecla == 'B') {
                    tecla = 0;
                    embrague_off();
                    servo_set(SERVO_CERRADO);
                    estado = ST_ESPERA;
                }
                if (tecla == 'C') {
                    tecla = 0;
                    embrague_off();
                    servo_set(SERVO_CERRADO);
                    estado = ST_MENU;
                }

                __delay_ms(200);    // 5 Hz
                break;

            // ------------------------------------------------
            case ST_COMPLETADO:
                leds_set(1, 0, 0);
                lcd_mostrar_completado();

                // Parpadeo LED verde 5x
                for (uint8_t i = 0; i < 5; i++) {
                    LED_VERDE = 0;
                    __delay_ms(300);
                    LED_VERDE = 1;
                    __delay_ms(300);
                }

                ok = false;
                while (!ok) {
                    if (emergency) { estado = ST_EMERGENCIA; break; }
                    __delay_ms(50);
                }
                if (estado == ST_EMERGENCIA) break;

                // Nueva tara para el siguiente bulto
                realizar_tara();
                leds_set(0, 0, 0);
                estado = ST_ESPERA;
                break;

            // ------------------------------------------------
            case ST_MENU:
                lcd_mostrar_menu();
                // Navegacion simple con teclado
                // TODO: implementar submenu completo en v1.1
                // Por ahora: cualquier tecla vuelve a ESPERA
                while (tecla == 0) {
                    if (emergency) { estado = ST_EMERGENCIA; break; }
                    __delay_ms(50);
                }
                if (estado == ST_EMERGENCIA) break;
                tecla = 0;
                estado = ST_ESPERA;
                break;

            // ------------------------------------------------
            case ST_EMERGENCIA:
                embrague_off();             // Refuerzo SW (HW ya actuo)
                servo_set(SERVO_CERRADO);
                leds_set(0, 0, 1);          // LED rojo
                lcd_mostrar_emergencia();

                // Buzzer continuo mientras E-Stop presionado
                while (!ESTOP_PIN) {
                    BUZZER_PIN = 1;
                    __delay_ms(200);
                    BUZZER_PIN = 0;
                    __delay_ms(200);
                }

                // E-Stop liberado
                BUZZER_PIN = 0;
                emergency  = false;
                LCD_I2C_Clear();
                LCD_I2C_SetCursor(0, 0);
                LCD_I2C_Print("E-Stop liberado ");
                LCD_I2C_SetCursor(0, 1);
                LCD_I2C_Print("Reiniciando...  ");
                __delay_ms(2000);
                realizar_tara();
                leds_set(0, 0, 0);
                estado = ST_ESPERA;
                break;

            // ------------------------------------------------
            case ST_INICIO:
            default:
                estado = ST_ESPERA;
                break;
        }
    }
}

// ============================================================
// INICIALIZACION
// ============================================================
void initPorts(void) {
    // Oscilador interno 8 MHz
    OSCCON = 0b01110010;    // IRCF=111 (8 MHz), IOFS

    // PORTA: RA4=ESTOP(entrada), RA5=START(entrada)
    TRISA  = 0b00110000;    // RA4, RA5 como entradas
    LATA   = 0;

    // PORTB: RB0-RB3 filas teclado (salida), RB4-RB7 columnas (entrada+KBI)
    TRISB  = 0b11110000;    // RB7:4 entradas, RB3:0 salidas
    LATB   = 0b11110000;    // Filas en HIGH (inactivo), pull-ups en cols
    RBPU   = 0;             // Activar pull-ups internos PORTB

    // PORTC: RC2/CCP1=servo(salida), RC3=SCL(I2C), RC4=SDA(I2C)
    TRISC  = 0b11011000;    // RC3,RC4 para I2C (MSSP los controla), RC2 salida PWM
    LATC   = 0;

    // PORTD: RD0=HX_SCK(salida), RD1=HX_DOUT(entrada), RD3-RD7=salidas
    TRISD  = 0b00000010;    // Solo RD1 como entrada (DOUT HX711)
    LATD   = 0;

    // PORTE: RE0=STOP(entrada)
    TRISE  = 0b00000001;    // RE0 como entrada
    LATE   = 0;

    // ADC desactivado (no se usa en este proyecto)
    ADCON0 = 0;
    ADCON1 = 0x0F;          // Todos los pines como digitales

    // I2C MSSP para LCD
    SSPCON1 = 0b00101000;   // I2C Master mode
    SSPADD  = 19;           // 100 kHz @ 8 MHz: (8e6/(4*100e3))-1 = 19
    SSPSTAT = 0b10000000;   // Slew rate control desactivado

    // Estado inicial actuadores
    SSR_PIN      = 0;       // Embrague desacoplado
    BUZZER_PIN   = 0;
    LED_VERDE    = 0;
    LED_AMARILLO = 0;
    LED_ROJO     = 0;

    __delay_ms(100);
}

void initInterrupts(void) {
    // Timer0: base de tiempo (~500 ms)
    T0CON  = 0b00000010;    // 16 bits, reloj interno, prescaler 1:8
    TMR0   = 49911;
    TMR0IF = 0;
    TMR0IE = 1;
    TMR0ON = 1;

    // PORTB KBI: deteccion de teclado matricial
    RBIF   = 0;
    RBIE   = 1;

    // Interrupciones globales
    PEIE   = 1;
    GIE    = 1;
}

void initPWM(void) {
    // CCP1 como PWM @ 50 Hz para servo MG996R
    // Fosc=8MHz, prescaler T2=1:16, PR2=249
    // f_PWM = Fosc / (4 * (PR2+1) * prescaler) = 8e6/(4*250*16) = 500 Hz... ajustar
    // Para 50 Hz: prescaler=1:16, PR2=249 -> f=8e6/(4*(249+1)*16)=50 Hz ✓
    PR2     = 249;
    T2CON   = 0b00000011;   // Timer2 ON, prescaler 1:16
    CCP1CON = 0b00001100;   // PWM mode
    CCPR1L  = SERVO_CERRADO;
    TMR2    = 0;
}

// ============================================================
// HX711 — LECTURA BIT-BANG SPI
// ============================================================
int32_t hx711_leer_raw(void) {
    int32_t raw = 0;

    GIE = 0;    // Deshabilitar IRQ durante lectura critica

    // Esperar a que HX711 este listo (DOUT = LOW)
    uint16_t timeout = 10000;
    while (HX_DOUT && timeout--);
    if (timeout == 0) {
        GIE = 1;
        return 0x7FFFFFFF;  // Error: HX711 no responde
    }

    // Leer 24 bits MSB primero
    for (uint8_t i = 0; i < 24; i++) {
        HX_SCK = 1;
        __delay_us(1);
        raw = (raw << 1) | (HX_DOUT ? 1 : 0);
        HX_SCK = 0;
        __delay_us(1);
    }

    // Pulso 25: selecciona ganancia 128x (canal A) para la proxima lectura
    HX_SCK = 1;
    __delay_us(1);
    HX_SCK = 0;
    __delay_us(1);

    GIE = 1;

    // Extension de signo de 24 a 32 bits
    if (raw & 0x800000) {
        raw |= (int32_t)0xFF000000;
    }

    return raw;
}

int32_t hx711_leer_promedio(uint8_t n) {
    int64_t suma = 0;
    uint8_t muestras_validas = 0;

    for (uint8_t i = 0; i < n; i++) {
        int32_t raw = hx711_leer_raw();
        // Descartar lecturas claramente erroneas
        if (raw != 0x7FFFFFFF && raw != (int32_t)0x800000) {
            suma += raw;
            muestras_validas++;
        }
        __delay_ms(12);     // 80 SPS → 12.5 ms/muestra
    }

    if (muestras_validas == 0) return 0;
    return (int32_t)(suma / muestras_validas);
}

float calcular_peso(int32_t raw) {
    int32_t neto = raw - offset_tara;
    if (neto < 0) neto = 0;
    float kg = (float)neto / factor_calibracion;
    if (kg > 60.0f) kg = 60.0f;
    return kg;
}

void realizar_tara(void) {
    LCD_I2C_Clear();
    LCD_I2C_SetCursor(0, 0);
    LCD_I2C_Print("Ejecutando tara ");
    LCD_I2C_SetCursor(0, 1);
    LCD_I2C_Print("No colocar peso ");

    // Descartar las primeras 4 muestras (estabilizacion del HX711)
    for (uint8_t i = 0; i < 4; i++) {
        hx711_leer_raw();
        __delay_ms(12);
    }

    // Tomar 32 muestras para la tara
    offset_tara = hx711_leer_promedio(32);

    // Guardar en EEPROM (3 bytes: HI, MID, LO)
    EEPROM_Write(0x03, (uint8_t)((offset_tara >> 16) & 0xFF));
    EEPROM_Write(0x04, (uint8_t)((offset_tara >>  8) & 0xFF));
    EEPROM_Write(0x05, (uint8_t)( offset_tara        & 0xFF));

    beep(200);
    LCD_I2C_Clear();
    LCD_I2C_SetCursor(0, 0);
    LCD_I2C_Print("Tara completada ");
    __delay_ms(1000);
}

// ============================================================
// LCD I2C — PANTALLAS
// ============================================================
void lcd_mostrar_espera(void) {
    LCD_I2C_SetCursor(0, 0);
    LCD_I2C_Print("DAMSPI-150[ESPER");
    LCD_I2C_SetCursor(0, 3);
    LCD_I2C_Print("A=Iniciar C=Menu");
}

void lcd_mostrar_peso(void) {
    // Mostrar peso actual en fila 1 con 3 decimales
    // Formateo manual ya que no hay printf en XC8 free
    uint32_t gramos = (uint32_t)(peso_kg * 1000.0f);
    uint8_t  kg_u   = (uint8_t)(gramos / 1000);
    uint16_t g_dec  = (uint16_t)(gramos % 1000);

    LCD_I2C_SetCursor(0, 1);
    LCD_I2C_Print("PESO:  ");
    // Escribir kg (0-60)
    LCD_I2C_WriteChar('0' + kg_u / 10);
    LCD_I2C_WriteChar('0' + kg_u % 10);
    LCD_I2C_WriteChar('.');
    LCD_I2C_WriteChar('0' + g_dec / 100);
    LCD_I2C_WriteChar('0' + (g_dec % 100) / 10);
    LCD_I2C_WriteChar('0' + g_dec % 10);
    LCD_I2C_Print(" kg   ");

    // Objetivo y bultos en fila 2
    LCD_I2C_SetCursor(0, 2);
    LCD_I2C_Print("OBJ:");
    LCD_I2C_WriteChar('0' + (uint8_t)peso_objetivo_kg / 10);
    LCD_I2C_WriteChar('0' + (uint8_t)peso_objetivo_kg % 10);
    LCD_I2C_Print("kg BLT:");
    LCD_I2C_WriteChar('0' + bultos / 100);
    LCD_I2C_WriteChar('0' + (bultos % 100) / 10);
    LCD_I2C_WriteChar('0' + bultos % 10);
}

void lcd_mostrar_completado(void) {
    LCD_I2C_Clear();
    LCD_I2C_SetCursor(0, 0);
    LCD_I2C_Print("** COMPLETADO! **");
    LCD_I2C_SetCursor(0, 1);
    LCD_I2C_Print("Bultos: ");
    LCD_I2C_WriteChar('0' + bultos / 100);
    LCD_I2C_WriteChar('0' + (bultos % 100) / 10);
    LCD_I2C_WriteChar('0' + bultos % 10);
    LCD_I2C_SetCursor(0, 2);
    LCD_I2C_Print("                    ");
    LCD_I2C_SetCursor(0, 3);
    LCD_I2C_Print("Presione D para cont");
}

void lcd_mostrar_emergencia(void) {
    LCD_I2C_Clear();
    LCD_I2C_SetCursor(0, 0);
    LCD_I2C_Print("** EMERGENCIA!! **");
    LCD_I2C_SetCursor(0, 1);
    LCD_I2C_Print("  E-STOP ACTIVO  ");
    LCD_I2C_SetCursor(0, 2);
    LCD_I2C_Print("Libere el boton  ");
    LCD_I2C_SetCursor(0, 3);
    LCD_I2C_Print("para continuar   ");
}

void lcd_mostrar_menu(void) {
    LCD_I2C_Clear();
    LCD_I2C_SetCursor(0, 0);
    LCD_I2C_Print(">>> MENU CONFIG ");
    LCD_I2C_SetCursor(0, 1);
    LCD_I2C_Print("> Peso objetivo ");
    LCD_I2C_SetCursor(0, 2);
    LCD_I2C_Print("  Tara manual   ");
    LCD_I2C_SetCursor(0, 3);
    LCD_I2C_Print("  Cualq.=Salir  ");
}

void lcd_mostrar_ask(void) {
    LCD_I2C_Clear();
    LCD_I2C_SetCursor(0, 0);
    LCD_I2C_Print("Peso objetivo:  ");
    LCD_I2C_SetCursor(0, 1);
    LCD_I2C_Print("___ kg (1-60)   ");
    LCD_I2C_SetCursor(0, 2);
    LCD_I2C_Print("                ");
    LCD_I2C_SetCursor(0, 3);
    LCD_I2C_Print("D=OK  #=Borrar  ");
}

// ============================================================
// TECLADO MATRICIAL 4x4 — ROW SCANNING
// ============================================================
uint8_t escanear_teclado(void) {
    // Mapa: {F1, F2, F3, F4} x {C1, C2, C3, C4}
    const uint8_t mapa[4][4] = {
        {'1', '2', '3', 'A'},
        {'4', '5', '6', 'B'},
        {'7', '8', '9', 'C'},
        {'*', '0', '#', 'D'}
    };

    for (uint8_t fila = 0; fila < 4; fila++) {
        // Activar fila (LOW activo)
        LATB = ~(1 << fila) & 0x0F;
        __delay_us(10);

        uint8_t cols = (PORTB >> 4) & 0x0F;

        if (cols != 0x0F) {
            for (uint8_t col = 0; col < 4; col++) {
                if (!(cols & (1 << col))) {
                    LATB = 0b11110000;  // Restaurar filas
                    return mapa[fila][col];
                }
            }
        }
    }

    LATB = 0b11110000;
    return 0;   // Sin tecla
}

void procesar_tecla(uint8_t t) {
    counter_inact = 0;      // Reiniciar inactividad

    if (t == 0) return;

    // E-Stop via teclado (tecla especial — definir cual en HW final)
    // Por ahora el E-Stop es solo hardware

    if (ask) {
        // Ingreso numerico del peso objetivo
        if (t >= '0' && t <= '9') {
            if (input_count < 2) {
                uint8_t digito = t - '0';
                objetivo_temp = objetivo_temp * 10 + digito;
                input_count++;
                // Actualizar LCD fila 1
                LCD_I2C_SetCursor(0, 1);
                LCD_I2C_WriteChar('0' + objetivo_temp / 10);
                LCD_I2C_WriteChar('0' + objetivo_temp % 10);
                LCD_I2C_Print(" kg         ");
            }
        } else if (t == '#') {
            // Borrar
            if (input_count > 0) {
                objetivo_temp /= 10;
                input_count--;
                LCD_I2C_SetCursor(0, 1);
                LCD_I2C_WriteChar('0' + objetivo_temp / 10);
                LCD_I2C_WriteChar('0' + objetivo_temp % 10);
                LCD_I2C_Print(" kg         ");
            }
        } else if (t == 'D') {
            ok = true;
        }
    } else {
        // Fuera de modo ASK: guardar tecla para FSM principal
        tecla = t;
        if (t == 'D') ok = true;
    }
}
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

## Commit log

2026-05-02 [Init] Repo Structure + Base for each area
    [BOM_Descascaradora_v1.xlsx, GANTT_Descascaradora_v2.xlsx]
2026-07-06 Archivos Kicad
    [BORNERA2.stp, BORNERA3.stp, BORNERA4.stp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]
